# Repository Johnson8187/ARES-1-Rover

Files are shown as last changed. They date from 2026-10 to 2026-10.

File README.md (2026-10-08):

# ARES-1 Rover

低成本、可在高中營隊實作的**直立式雙履帶火星探測車**。主版本 B：WALL·E 式的直立身體與可左右轉的頭，
但把工程放在前面：兩顆 JGA25-370 對角擺放、底盤做成雙層巴士讓學員自備的行動電源躺在馬達正上方、頭部伺服只負責轉不負責扛。

**整台車是 3 mm 椴木合板雷切＋白膠，零 3D 列印**：46 片合板，30 × 45 cm 的板子一台 2 張（**3 台一起排只要 5 張**）、雷射約 30 分鐘就切完一台；履帶和輪子用廠商套件。

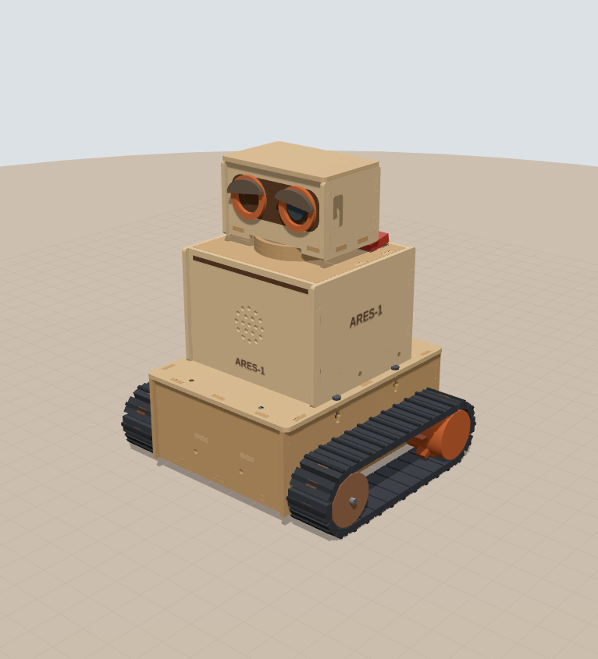
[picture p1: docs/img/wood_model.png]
木板版 3D 模型


| | |
|---|---|
| 外形 | 179 × 160 × 207 mm，約 955 g（含 10000 mAh 行動電源），重心高 61 mm |
| 結構 | 3 mm 椴木合板 46 片，榫接＋白膠；切縫補償、榫孔間隙都可在網頁調，SVG／DXF 直接下載 |
| 驅動 | 2 × JGA25-370 6 V（霍爾編碼器回授）＋ DRV8870 雙路，廠商履帶套件（可拼接，尺寸待量測） |
| 大腦／眼睛 | GOOUUU ESP32-S3-CAM 整塊裝在頭裡，真鏡頭就在右眼，跟頭一起轉 |
| 頭部 | SG92R 直接由 ESP32 驅動（不需伺服驅動板），±45°（機械限位 ±55°） |
| 聲音 | INMP441（頭部）＋ MAX98357A ＋ Ø40 喇叭，I2S 共用時脈 |
| 電源 | 學員自備 PD 行動電源（電池艙 85 × 27.5、尾端開放）→ CH224K 誘騙 9 V → DRV8870（PWM 上限 66 %）＋ Mini560 5 V；編碼器 3.3 V 由 AMS1117 供應 |

## 內容

| 路徑 | 說明 |
|---|---|
| [`web/index.html`](web/index.html) | 互動式 3D 工程網頁（Three.js）：視角、爆炸圖、透明外殼、剖面、配線、點選規格、參數調整、干涉檢查、重心、鏡頭視野、組裝步驟、**雷切排版與 SVG／DXF 下載** |
| [`laser/`](laser) | 預設參數的雷切檔（30 × 45 cm 板）：切縫測試片、一台 2 張、3 台一起 5 張，SVG＋DXF；`parts.csv` 零件清單；`export.mjs` 重產工具 |
| [`docs/LASER.md`](docs/LASER.md) | **雷切與組裝指南**：測試片怎麼量、雷切設定、哪裡上膠、常見問題 |
| [`docs/DESIGN.md`](docs/DESIGN.md) | 工程設計書：方案比較、分層、旋轉機構、穩定性、配線與 GPIO、尺寸狀態、風險、待補量清單、BOM、組裝 |
| [`cad/`](cad)、[`docs/PRINTING.md`](docs/PRINTING.md) | **備案**：改木板之前的 3D 列印版（OpenSCAD＋STL＋試配套件），幾何跟現在的木板版不完全一樣 |
| [`firmware/ares1_bringup/`](firmware/ares1_bringup) | 腳位定義＋硬體上線測試程式（馬達、伺服、喇叭、麥克風、9 V 電源監測、編碼器堵轉保護） |

## 快速開始

1. 用瀏覽器打開 `web/index.html`（需要網路載入 Three.js）。
2. 「參數 → 行動電源」選或輸入自己那一顆的尺寸，看「檢查」分頁的電池艙、干涉與穩定性結果；「規格」分頁有待量測清單。
3. 要雷切時先看 [`docs/LASER.md`](docs/LASER.md)：先切 `laser/ARES1_test.svg` 量板厚和切縫，填進網頁「雷切」分頁，再下載正式板的 SVG／DXF。
4. 組裝照網頁「組裝」分頁的 16 步；哪裡上膠、哪裡不要上膠見 `docs/LASER.md` 第 5 節。

> 已依商品圖更新 ESP32-S3-CAM（GOOUUU）、JGA25-370、DRV8870、MAX98357A、INMP441、SG92R。
> 仍待量測：**履帶套件的輪徑與中心孔（決定底盤高度）**、CH224K 的 9 V 設定方式、DRV8870 的 VO 是否為限流電壓、學員行動電源尺寸、鏡頭實際位置、減速比、6P 編碼器線腳位、喇叭型式等，詳見 `docs/DESIGN.md` 第 11 節。履帶套件量好之前，先切測試片和頭、身體練手，底盤箱等尺寸改好再切。
> ⚠ CH224K 誘騙板上車前一定要先量到 9.0 V（出廠常是 20 V）。

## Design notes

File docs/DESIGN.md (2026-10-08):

# ARES-1 工程設計書 · 主版本 B（直立式、頭可轉、雙履帶）

> 一句話：把兩顆 64 mm 長的馬達「一前一後斜對角」塞進 110 mm 寬的底盤，底盤做成雙層巴士——
> 下層是馬達和電路，上層整層是學員自備行動電源的「床」，從車尾推進去、長的可以露出尾巴。
> 一顆 13 g 的伺服只負責「轉」、不負責「扛」。直立式的角色感留給頭和身體，穩定性交給底盤。

> 整台車是 **3 mm 椴木合板雷切＋白膠**，46 片、30 × 45 cm 兩張板（3 台一起排 5 張），零 3D 列印（切法與組裝見 [`LASER.md`](LASER.md)）。

木板版 3D 模型

| 項目 | 數值 | 狀態 |
|---|---|---|
| 外形 W × L × H | 179 × 160 × 207 mm | 設計值 |
| 結構 | 3 mm 椴木合板 46 片，榫接＋白膠；一台兩張 30 × 45 cm 板（3 台 5 張） | 設計值 |
| 估計重量 | 約 955 g（含 10000 mAh 薄型行動電源 215 g；合板約 260 g） | 估計 |
| 重心高度 | 60.7 mm（總高 29%） | 估計 |
| 翻覆角 前／後／側 | 42.8° ／ 42.3° ／ 55.7° | 估計 |
| 電源 | 學員自備 PD 行動電源 → CH224K 誘騙 9 V → DRV8870＋Mini560 5 V | 設計值 |
| 續航 | 約 5.4 h（10000 mAh、平均 5.8 W） | 估計 |
| 離地間隙 | 11.0 mm（側壁下緣） | 設計值 |
| 頭部轉角 | ±45°（機械限位 ±55°） | 設計值 |
| 鏡頭 | 在右眼，離地約 184 mm，俯角 10° | 設計值 |
| 履帶 | 廠商套件（可拼接）；模型暫用節距 12.5、寬 30、每邊 28 節 | 待量測 |

互動式 3D 模型：`web/index.html`（直接用瀏覽器開，需要網路載入 Three.js）。
雷切檔：`laser/`（預設參數的 SVG／DXF），或在網頁「雷切」分頁改板厚、切縫、板材大小後直接下載。
3D 列印版（`cad/`、`PRINTING.md`）保留當備案，幾何是改木板之前的版本。

尺寸標記：**[C] 已確認**（你提供的或商品圖）、**[E] 估計**、**[M] 待量測**、**[D] 設計值**（我選的，可以改）。

### 目前已依實物資料更新的零件

| 零件 | 從照片確認的事 |
|---|---|
| GOOUUU ESP32-S3-CAM（N16R8） | 2 × 20 排針絲印、OTG＋TTL 兩個 USB-C 在同一端、板載 WS2812、天線突出 PCB 約 4 mm、**相機是軟排線接的，平常貼在模組鐵殼上，偏天線端約 20 mm** |
| JGA25-370 | **6 V 版**、軸根 Ø7 銅套、D 切面 3.5、M3 孔距 17、編碼器 6P 接頭在編碼器蓋側面 |
| DRV8870 雙路模組 | 端子 VM G OUT1–4 在一條長邊、排針 IN1–4 VO G S1 G S2 G 在另一條長邊、板上 LM317M 可調輸出 VO、0.1 Ω 取樣電阻 |
| MAX98357A | 腳位 LRC BCLK DIN GAIN SD GND Vin，上方兩孔距 12.6、孔心到底邊 16.7 |
| INMP441 | 10 × 10，腳位 L/R WS SCK｜GND VDD SD，收音孔在元件面（金屬殼上） |
| SG92R | 23.2 × 12.1 × 22.7、耳片跨距 32.1、含軸總高 30.5、含線約 13 g |

---

## 0. 常見問題（先回答你問的）

### 3D 列印太貴，改成木板雷切可以嗎？

**可以，而且整台車都改成雷切了。** 3 mm 椴木合板榫接＋白膠，46 片、30 × 45 cm 兩張板，雷射約 30 分鐘。
列印最貴的其實不是線材，是**機器時間**：一台車要印十幾到二十幾小時，十台就是一台印表機印一週；雷切一個下午切完全部。

改成木板時重新設計的地方：

| 原本（列印） | 現在（合板） | 為什麼 |
|---|---|---|
| 一體成形底盤槽 | 底板＋左右側壁＋前後壁榫接成箱子，側壁在最外層兼馬達座 | 平板只能做「箱子」，馬達孔、惰輪長槽都直接切在側壁上 |
| 4 根立柱＋熱熔螺母 | 側壁頂邊 4 個 **T 型槽**（M3 螺帽塞進橫槽），上身底板從上面鎖 | 雷切木作的標準鎖法，不用烙鐵 |
| 列印托盤＋M2.5 自攻 | 合板托盤，前端榫頭插前壁、後端落在後壁開口，**不上膠不鎖** | 要修下層的線，抬起來就拿出來 |
| 喇叭墊高環 | 喇叭直接黏在外殼前板背面 | 前板就是音箱面板，少一個零件 |
| 頸座軸環（一體） | 兩片合板環疊黏在頂板上，對位圓用雷射淺劃 | 木頭磨木頭：砂紙磨順＋抹蠟 |
| 頭罩＋後蓋（PETG） | 四面牆＋底板榫接；上蓋＋定位板直接卡進去，不用螺絲 | 臉上的護目鏡用雷雕，眼睛是黏上去的小件 |
| ESP32 角座 | 兩片卡板，PCB 兩端卡進十字孔 | 十字孔中間讓出 USB 與天線 |
| 列印履帶與鏈輪 | 廠商履帶套件 | 營隊已經買了 |

雷切檔是**從 3D 模型直接產生**的：每個榫頭穿過哪一片板，程式就在那片板上挖榫孔（每邊留 0.05 mm），再加上切縫補償、真實形狀排版（小零件塞進大零件的孔和缺口）、文字轉外框。
改任何參數（包括實測板厚），模型、檢查、雷切檔一起變。網頁「檢查 → 製造」會確認每個榫頭都有榫孔、孔不會破邊、孔跟孔不會黏在一起，並把 46 片板在 3D 裡每 2 mm 掃一次，確認沒有兩片佔到同一個空間（這一步抓到了頭部裙邊撞到前後牆下緣，已經在牆下緣挖缺口解決）。

### 新電源方案（PD 行動電源 → CH224K 9 V）可行嗎？

**可行，而且比 2S 18650 更適合營隊**：不用管鋰電池充電與保護板，學員帶自己的行動電源就好。但有 5 件事一定要做對：

| # | 風險 | 做法 |
|---|---|---|
| 1 | CH224K 板子出廠常設 **20 V 或 12 V** | 上車前先單獨接行動電源，三用電表量到 **9.0 V** 才接（設定方式要看你那塊板子：跳線、電阻或撥碼）[M] |
| 2 | 行動電源不支援 PD、或用了 A-to-C 線 → 只有 5 V | DRV8870 要 ≥ 6.5 V 才會動。GPIO1 量 9 V 匯流排，**< 7 V 就停車、亮紅燈、序列埠提示「PD 沒成功」** |
| 3 | 20 W 上限（9 V 最多 2.2 A） | 平常約 6 W 沒問題；最壞（兩邊堵轉＋伺服堵轉＋喇叭大聲）約 25 W。驅動板可變電阻轉最小（限流約 1.25 A）＋ PWM 上限 66 % ＋ **編碼器堵轉保護 0.3 s 斷電** |
| 4 | 行動電源電流太小會自動關機 | ESP32＋相機平常 9 V 端約 0.1 A，勉強在門檻上。韌體不用 deep sleep；真的被關掉就按一下行動電源 |
| 5 | 馬達是 6 V | 9 V × PWM 66 % ≈ 6 V；0.25 s 軟啟動。韌體 `MOTOR_MAX = 0.66`，不要拿掉 |

另外兩個重要修正：

- **編碼器的 3.3 V 改用 AMS1117-3.3**（從 Mini560 的 5 V 降）。DRV8870 模組的 VO 很可能就是晶片的 VREF（限流設定）：0.1 Ω 取樣下限流 ≈ VO ÷ 1 Ω，LM317M 最低 1.25 V → 最低 1.25 A。所以 **VO 不要拿去接任何東西，可變電阻轉到最小**（最安全的限流）。這點等板子回來用三用電表確認 [M]。
- **9 V 側加 C1 1000 µF／25 V**，並在 DRV8870 的 VM／G 端子上。馬達啟動、反轉的電流尖峰會讓行動電源以為短路而斷電，這顆電容幫它擋掉。

### 行動電源要放哪？掛在外面不是比較好換嗎？

我在模型裡兩種都算了（網頁「參數 → 行動電源 → 掛背後（比較用）」可以直接切）。同一顆 10000 mAh 薄型、總高相同：

| | **放電池艙（主方案）** | 掛在身體背後 |
|---|---|---|
| 重心高 | **60.7 mm** | 72.3 mm（＋12） |
| 重心前後 | 幾乎在兩軸中間（−0.5 mm） | 往後 15.7 mm |
| 急加速後仰門檻 | **8.9 m/s²** | 5.4 m/s² |
| 履帶最大抓地 μg | 6.9 m/s² | 6.9 m/s² |
| 結果 | 抓地力先打滑，不會翻 | **猛加速或上坡會往後翻**（後翻角 29.0°，比打滑角 35° 還小） |

掛背後唯一的好處是好拿，但重心又高又偏後，還會擋住外殼拆裝。**電池艙其實一樣好換**：拔線、撕開魔鬼氈、往後抽，不用拆任何東西。

### 每個學員的行動電源都不一樣大，怎麼辦？

把底盤想成**雙層巴士**：下層是馬達、驅動板、電源區；上層整層都是行動電源的「床」。

- **寬 85 mm × 高 27.5 mm 以內都放得進去**（左壁凸緣到右緣立板 85、托盤到上身底板 28）。市售 5000–20000 mAh 幾乎都在這個範圍。
- **長度不限：後面整個打開（開尾）**。電池艙長 152 mm，比較長的直接從車尾露出來；離去角在露出 40 mm 內都還有 36° 以上，營隊坡道 ≤ 20° 沒問題。
- **太薄**：兩條 20 mm 背對背魔鬼氈穿過托盤側邊的扣孔拉緊。
- **太短**：前面塞合板疊片（3 mm 一片可疊，或一塊泡棉），把它推回中間。網頁「檢查 → 行動電源前後位置」會算建議長度。

| 常見行動電源（典型值） | 外形 | 重量 | 重心高 | 建議前方墊塊 | 續航 |
|---|---|---|---|---|---|
| 5000 mAh 小型 | 98 × 63 × 15 | 120 g | 62.1 mm | 約 20 mm | 約 2.7 h |
| 10000 mAh 方塊 | 105 × 66 × 25 | 200 g | 62.1 mm | 約 20 mm | 約 5.4 h |
| **10000 mAh 薄型（預設）** | 148 × 70 × 15 | 215 g | 60.7 mm | 不用 | 約 5.4 h |
| 20000 mAh 大容量 | 155 × 74 × 27 | 420 g | 60.7 mm | 不用（尾巴露出 3 mm） | 約 10.8 h |

自己那一顆不在表上？網頁「參數 → 行動電源」直接輸入長寬厚和重量，所有檢查會即時重算。

**行動電源的條件**：支援 USB PD、背面標示有 **9V⎓2A**（或寫 18 W／20 W 以上）、有 **C 孔輸出**。只有 A 孔、或只有 5 V 的不能用。

### 怎麼換行動電源？

1. 關掉頂板上的開關。
2. 拔掉車尾的 USB-C 短線。
3. 撕開兩條魔鬼氈。
4. 行動電源直接往後抽出來，換一顆推到底、綁好、插線。

整個過程**不用拆外殼、不用拆頭、也不用把車翻過來**。不想拔也可以：輸入孔朝後放，直接插充電器在車上充。
網頁「顯示 → 換行動電源示範」會把這個動作跑給你看。

### SG92R 夠力嗎？要不要換 MG996R？

**SG92R 夠，而且比 MG996R 更適合。**

- 頭部（合板頭殼＋底盤＋ESP32＋麥克風＋線）約 70 g，轉動慣量約 50 kg·mm²。
- 就算用 SG92R 最快的速度（0.1 s／60°）急轉急停，只需要約 21 mN·m；SG92R 在 4.8 V 約 245 mN·m，**安全係數約 12 倍**。
- 頭的重量和撞擊由頂板的軸環／頭部裙邊承受，伺服軸只負責轉，不會被壓歪。

MG996R 反而是負擔：55 g（重心變高）、堵轉電流約 2.5 A（20 W 行動電源更吃緊、ESP32 容易重開機）、尺寸大到頸部要重畫，而且便宜版常有抖動。
MG996R 可以留給未來真的要扛東西的手臂。

### 一顆伺服需要伺服驅動板嗎？

**不需要。** ESP32-S3 的 LEDC 可以直接輸出 50 Hz PWM，SG92R 吃 3.3 V 訊號沒問題。只要注意：

- 伺服的電源（紅線）接配電板的 5 V，**不要**從 ESP32 的 5V 腳取電。
- 伺服的地（棕線）和 ESP32 共地。
- 訊號（橘線）接 GPIO2。

LU9685 這類 16 路 PWM 板是給「很多顆伺服」或「沒有 PWM 腳」的情況，這台車用不到。

### 馬達的霍爾編碼器要接回 ESP32-S3

可以，而且值得：有了速度回授，兩邊履帶可以跑一樣快，車子才走得直；新電源方案還要靠它做堵轉保護。做法見第 7.3 節，重點是：

- **A 相先接**：左馬達 → GPIO19、右馬達 → GPIO20（OTG 口的腳位，所以改用 TTL 口燒錄）。方向用馬達指令判斷就好。
- **B 相選配**：GPIO3、GPIO46。GPIO46 在燒錄時必須是低電位，燒不進去時拔掉 J2 或把輪子轉一下。
- **編碼器一定要吃 3.3 V**：ESP32-S3 的腳位不耐 5 V。由 AMS1117-3.3 供電，每條訊號線再串 1 kΩ。

---

## 1. 三種直立式配置，為什麼選 B

| | A 同軸後置 | **B 對角馬達（主方案）** | C 長頸桅杆 |
|---|---|---|---|
| 馬達擺法 | 兩顆都在車尾、同一軸線對頂 | 左馬達在後、右馬達在前，前後錯開 | 同 B |
| 兩馬達干涉 | 內寬 110 會**重疊 18 mm**，要加寬到 ≥ 132 | **完全錯開**，最近距離 86.5 mm | 同 B |
| 整車寬 | 205 mm | **181 mm** | 181 mm |
| 重心 | 偏後 8 mm | 前後平衡（z 偏移 −0.6 mm） | 高 10 mm（71.6 mm） |
| 換行動電源 | 電池艙同 B，但車尾下層被馬達佔滿，USB-C 只能接到前面 | **車尾抽出，長的可以露出尾巴** | 同 B |
| 頭部 | 同 B | 線束最短、最穩 | 桅杆會晃、線束多 70 mm |
| 鏡頭 | 同 B | 離地 182 mm | 離地 252 mm，看得最遠 |
| 結論 | 不選 | **主方案** | 備選：比賽需要看遠時再用 |

C 其實不會翻（翻覆門檻 7.6 m/s² 仍大於抓地力 6.9 m/s²），但安全餘裕從 27% 掉到 10%，而且頭部多一根 70 mm 的槓桿，每次急停都會點頭。

網頁「參數 → 配置方案」可以切換 A/B/C，A 在 110 mm 內寬時會直接亮紅色干涉。

---

## 2. 分層與高度

座標：X＝車子左側、Y＝向上、Z＝車頭方向，原點在地面中心。

| 層 | 高度範圍 (mm) | 內容 |
|---|---|---|
| 底盤下層 | 0 – 37.5 | 履帶、底盤箱（合板榫接）、兩顆 JGA25-370、DRV8870＋C1、電源區（CH224K、Mini560、AMS1117） |
| 底盤上層（電池艙） | 37.5 – 70 | 托盤、行動電源、魔鬼氈；右側線材通道與 J1/J2；上身底板 |
| 身體層 | 71.5 – 149.5 | 上身骨架、外殼套筒（高 78）、喇叭、MAX98357A、配電板、開關、SG92R |
| 頭部層 | 149.5 – 207 | 頸座軸環、頭部底盤、頭殼、上蓋、ESP32-S3-CAM、INMP441 |

關鍵高度：軸心 24.2、馬達頂 36.7、履帶頂 48.5；側壁下緣 11.0、底板 14–17、托盤 37.5–40.5、電池艙 40.5–68.5、上身底板 68.5–71.5；
身體 71.5–149.5；伺服底 128.1、舵盤頂＝頭部底板底 159.0、鏡頭中心 184.0、頭頂 207.0。

為了讓出 28 mm 的電池艙，身體從 96 縮成 78 mm，**總高不變**。降壓模組搬到底盤電源區，身體裡反而更空。

---

## 3. 底盤層

### 3.1 履帶與輪子（廠商套件）

營隊已經買了履帶套件：履帶是一節一節拼的，長度可以自己加減。模型暫時用「節距 12.5、10 齒驅動輪（節圓 Ø41）、寬 30、軸距 111.5 → 每邊 28 節」算，
**輪徑決定輪軸高度、底盤箱高度和離地間隙**，套件量好之後要改參數（網頁「參數」）再切底盤箱。

要量的：驅動輪外徑（含齒）、齒數、輪寬、中心孔（圓／D 形／六角、幾 mm）；惰輪外徑、寬、中心孔；履帶節距（量 10 節 ÷ 10）、寬、厚。
驅動輪中心孔不是 Ø4 D 形的話，用聯軸器或法蘭轉接到 JGA25-370 的軸。

### 3.2 底盤箱與馬達固定

- 底盤箱是 14 片 3 mm 合板：底板夾在四面牆中間、四邊榫頭插進牆；**左右側壁在最外層**，前後各多 3 mm 包住前後壁，同時是馬達座與惰輪軸座。
- 左馬達在車尾（z = −55.75），右馬達在車頭（z = +55.75）。兩個 M3 孔（孔距 17）**左右（水平）排列**，編碼器 6P 接頭水平朝車身中央（上面 0.8 mm 就是托盤）。
- 用 **M3 × 6 圓頭** 從側壁外面鎖，穿過 3 mm 合板後進入減速箱約 3 mm。軸根 Ø7 銅套凸台坐進側壁 Ø8.4 軸孔。
- 馬達尾端靠在兩片合板托柱上，束線帶綁住。底板在馬達正下方開缺口，讓馬達低到「軸高 − 半徑」。
- 側壁比底板往下多 3 mm（底板的榫頭才插得進側壁），所以離地間隙是 11.0 mm，由側壁下緣決定。

### 3.3 上身怎麼鎖在底盤上：T 型槽

側壁頂邊有 4 個 T 型槽（左右各 2，z = ±30）：豎槽 3.4 寬、13 深，中間一條 5.8 × 2.6 的橫槽放 M3 螺帽。
上身底板（比側壁外面再寬 2.5 mm）從上面用 **M3 × 12** 鎖下來咬住螺帽。螺帽比 3 mm 板寬，會凸出側壁兩面一點點，這是正常的。

### 3.4 電池艙（行動電源）

| 項目 | 設計 |
|---|---|
| 托盤 | 3 mm 合板、底面在 37.5（馬達頂 +0.8）；前端兩個榫頭插進前壁，左邊架在凸緣上、右邊靠小立板、後端落在後壁開口下緣。**不上膠不鎖**，抬起來就拿出來 |
| 可用空間 | 寬 85（右緣立板到左壁凸緣）× 高 27.5 × 長 152，**後方不封口** |
| 擋塊 | 前壁就是擋塊；短的行動電源前面塞合板疊片（3 mm 一片）或泡棉 |
| 固定 | 兩條 20 mm 背對背魔鬼氈，扣孔 3 組（z = −55、−10、35），行動電源短的時候用前面兩組 |
| 右緣立板 | 高 8，黏在托盤上，兼行動電源導軌與線材通道的牆 |
| 線材通道 | 右側 16 mm 寬，從地板直通上身底板的 6 × 26 長孔；J1/J2 放在裡面 |
| 後壁 | 上半部整個打開（行動電源進出）；下半部 13.5 × 7.6 孔讓 CH224K 的 USB-C 母座伸出 |

### 3.5 DRV8870 雙路模組

| 項目 | 設計 |
|---|---|
| 位置 | **右側** x = −51 … −21、z = −36 … 12；底板開 4 個 Ø3.2 孔，5 mm 尼龍隔離柱墊高，M3 從底板下面鎖 |
| 孔距 | 40.8 × 22.8（照片標 R3.6 圓角，孔心在圓角中心）[E] |
| 方向 | **藍色端子朝車身中央、VM 在後端（靠電源區）**；排針那一長邊在線材通道正下方，杜邦頭上方有 30 mm 可以往上彎線 |
| 接線 | VM／G ← 9V_SW（並 C1 1000 µF）；OUT1/2 → 右（前）馬達；OUT3/4 → 左（後）馬達；IN1–4 ← J2 |
| VO | **不接任何東西**。很可能就是 VREF（限流）：可變電阻轉到最小 ≈ 1.25 A [M] |
| S1／S2 | 用途待確認（可能是電流取樣輸出），第一版不接 |

控制：IN1 = PWM、IN2 = 0 前進；IN1 = 0、IN2 = PWM 後退；兩腳都 0 滑行、都 1 煞車。

### 3.6 電源區（下層右後角）

| 模組 | 位置 | 說明 |
|---|---|---|
| CH224K 誘騙板 | 右後角，坐在合板墊片上、USB-C 母座從後壁小孔伸出 | 設 9 V；外形約 12 × 25 [M] |
| Mini560 | CH224K 旁邊 | 9 V → 5 V，標示 5 A [E]；固定 5 V 版免調 |
| AMS1117-3.3 | 右側通道下方 | 5 V → 3.3 V，只給兩顆編碼器 |
| C1 1000 µF／25 V | 躺在 DRV8870 端子旁、腳朝後 | 並在 VM／G 上 |

行動電源的 C 孔朝後，用 10–15 cm 的 C-to-C 短線從車尾繞下來插 CH224K。桌上測試時可以直接插 PD 充電頭（20 W 以上）。
底板上雷雕了每個模組的位置框（藍色淺劃線）：先黏 3 mm 合板墊片，再用泡棉雙面膠貼模組（Mini560、AMS1117 多半沒有安裝孔）。

---

## 4. 身體層

- **上身骨架**：上身底板（161 × 121 × 3）兼電池艙上蓋；一片脊板＋兩片側翼用榫頭插進底板和頂板，白膠固定。右後方 6 × 26 長孔對準線材通道。拆 4 顆 M3（T 型槽），上身（含頭）整組拿起，中間只連 J1（電源）、J2（馬達與編碼器訊號）。
- **外殼套筒**：110 × 100 × 78、上下開口，左右側板在最外層、前後板內縮 3 mm（像相框）。側面 4 顆 M3 × 8 鎖進側翼上壓入的六角螺帽。頭 84 × 54、軸環 Ø50、限位柱半徑 33，全在開口之內，**拆外殼不用拆頭**。

| 模組 | 位置 | 固定 |
|---|---|---|
| 喇叭 Ø40 × 20 [E] | 外殼前板背面，對準圓孔格柵 | 熱熔膠黏在前板上（線留 12 cm，外殼才拔得起來） |
| MAX98357A | 喇叭旁，喇叭線 < 8 cm | 上方兩孔 M2（孔距 12.6 [C]） |
| 配電洞洞板 | 右翼內側（SS34、470 µF ×2、9 V 監測分壓、4 顆 1 kΩ 編碼器保護電阻） | 束線帶穿右翼的 4 個小孔 |
| 開關 KCD1 | 頂板左後角，按鈕朝上 | 卡入 19 × 13 開孔 |
| SG92R | 倒吊在頂板下方 | 耳片 2 × M2 自攻 |

⚠ 你的 MAX98357A 商品組合裡附的是**長方形腔體喇叭**。如果你用的是那一顆而不是 Ø40 圓形喇叭，請告訴我尺寸，前板的格柵要改成長方形。

---

## 5. 頭部層（主版本重點）

### 5.1 頭型：右眼就是真鏡頭

GOOUUU 板的 OV2640 不是焊死在板子中間，而是用橘色軟排線接在板子中段的 FPC 座，相機本體平常貼在 WROOM 模組的鐵殼上，
**離 PCB 中心約 20 mm、偏天線那一端**。PCB 橫放在頭裡時，這個位置剛好就是一隻眼睛。

所以頭部設計成一對對稱的眼圈：**右眼的瞳孔就是真的鏡頭**，左眼是合板切的造型瞳孔（塗深灰）。臉上一片深色護目鏡是雷雕出來的。
兩眼上方各有一片可替換的眼瞼，角度就是表情，營隊可以讓學員自己設計。

軟排線的好處：鏡頭和眼圈中心差幾 mm 時，直接把相機模組挪過去，用雙面膠貼好就對準了。
（網頁「鏡頭偏離 PCB 中心」小於 12 mm 時，會自動退回「兩眼都是造型、鏡頭藏在護目鏡中間」的版本。）

### 5.2 旋轉機構：伺服只轉、不扛

```
頭部底板（合板）──┬── 2×M2 ── Ø20 圓舵盤 ── SG92R 花鍵
                  └── 裙邊 3 片疊黏 ID51/OD57（下垂 9）── 套住 ──> 頸座軸環 2 片疊黏 ID42/OD50（高 6）
```

- 伺服從頂板下方塞入，耳片貼頂板底面，只有花鍵凸台露出來。
- 頭的重量由花鍵承受（約 70 g），**側向力與撞擊由軸環／裙邊承受**，徑向間隙 0.5 mm。木頭磨木頭：兩邊都用 400 號砂紙磨順、抹一點蠟。
- 兩根限位柱＋裙邊限位指：軟體 ±45°、**機械限位 ±55°**。
- 裙邊 Ø57 比頭部深度（54）大一點，前面會像下巴一樣露出約 2.5 mm；最上面那片裙邊跟頭殼前後牆的下緣同高，所以前後牆下緣各挖一個缺口讓它通過（3D 互撞檢查抓到的）。
- 組裝時先用測試程式把伺服轉到 90° 再裝舵盤。

### 5.3 線束怎麼過一個被伺服佔住的轉軸

1. 頭部底板在轉軸後方 16 mm 開 Ø8 孔（杜邦頭可以一顆一顆穿）。
2. 頂板同一位置開**腎形窗口**（r = 9 … 20.5，只在 z ≤ −7.5，避開伺服耳片）。
3. 線束現在是 15 芯（加了編碼器），外包螺旋套約 Ø7。頭轉到 ±45° 時線束邊緣在 57.6°，窗口可用到 62.1° → **餘裕 4.4°**。
4. 身體內留 U 形餘長圈。頭轉 ±45° 時線束頂端只橫移約 ±11 mm。

### 5.4 ESP32-S3-CAM 安裝（GOOUUU）

- PCB 橫放、俯角 10°。USB 端朝頭部**左側**、天線端朝**右側**（天線突出 PCB 約 4 mm，右側牆內還有 1.9 mm 空隙）。
- 兩片合板卡板插在頭部底板上，PCB 兩端卡進卡板的十字孔（上下角卡住，中間讓出 USB 與天線）。先把 PCB 塞進兩片卡板，再三個一起插進底板。
- 排針朝後，杜邦頭插好後點熱熔膠。深度預算：鏡頭 11 [M] ＋ PCB 1.6 ＋ 排針 8.5 ＋ 杜邦 14 ＋ 彎線 6 = 41.1，頭內可用 44.5 mm。
- **板上只有一支 GND**（右排最下面）：5V 與 GND 用 24 AWG，麥克風的 GND 從同一點分出來。
- USB：頭殼左側板 9 × 20 mm 開孔，OTG、TTL 兩個 USB-C 都露出來。**用 TTL 口燒錄**（CH340 會自動重置，最穩）。
- 散熱：頭後板 7 道散熱槽；木頭不像 PLA 會在 55 °C 變軟。

### 5.5 麥克風放頭部

| 位置 | 到喇叭 | 到馬達 | 結構振動 |
|---|---|---|---|
| **頭頂內側（預設）** | 109 mm | 181 mm | 和喇叭隔著伺服，不共振 |
| 身體上後方 | 約 104 mm | 約 136 mm | 和喇叭共用外殼，會收到喇叭振動 |

INMP441 的收音孔在元件面（金屬殼上），所以**金屬殼朝上**貼在頭頂 3 個 Ø1.5 小孔下面。排針不要焊，5 條線直接焊在焊盤上比較薄。
轉頭就是「轉耳朵」。網頁可以切回身體版本。

### 5.6 鏡頭視野

OV2640 對角約 66° [M] → 水平約 55°、垂直約 43°。俯角 10° 時正前方地面最近看到約 299 mm；頭轉 0° 與 45° 時畫面都不會拍到車身。

---

## 6. 特別檢查（你點名的 5 項）

| # | 檢查 | 結論 | 數字 |
|---|---|---|---|
| 1 | 兩顆 JGA25-370 是否干涉 | **不干涉** | 對角擺放，前後相距 86.5 mm；馬達尾端離對側側壁 46 mm。同軸擺法在 110 mm 內寬會重疊 18 mm |
| 2 | 頭轉時 ESP32 與線材會不會卡 | **不會** | PCB 在頭內跟著轉；15 芯線束窗口餘裕 4.4°；頭底離身體頂 9.5 mm |
| 3 | 重心是否過高 | **不高** | 重心 60.7 mm，只有總高 29%。行動電源躺在 40.5–55.5 mm、馬達與履帶在 37 mm 以下 |
| 4 | 底盤寬度是否撐得住 | **撐得住** | 側翻角 55.7°；前後翻門檻 8.9–9.1 m/s²，大於履帶最大抓地 6.9 m/s²，會先打滑不會翻 |
| 5 | 換電池與 USB | **方便** | 行動電源從車尾抽出；USB 從頭部左側直接插 |

穩定性算法：把 34 個零件的質量與位置加權求重心；支撐面取履帶外緣（x = ±90.5）與兩輪軸心（z = ±55.75）。
翻覆加速度 = g × 水平距離 ÷ 重心高；履帶最大加速度 ≈ μg（μ = 0.7 [E]）。韌體仍限制加速度（上線測試程式 0 → 全速 0.25 s），因為坡道、推土板、撞牆都會吃掉餘裕。

---

## 7. 配線設計

### 7.1 電源樹

```
學員自備 PD 行動電源（C 孔）
 └─ C-to-C 短線 ─ 後壁 USB-C ─ CH224K 誘騙 9 V ─ J1（9V_RAW）─ 頂板開關 ─ J1（9V_SW）
      ├─ C1 1000 µF／25 V ─ DRV8870 VM（馬達，PWM 上限 66 %；VO 不接、可變電阻最小）
      ├─ Mini560 IN → 5 V ─ J1（5 V × 2 pin）
      │    ├─ AMS1117-3.3 → 兩顆馬達編碼器 VCC
      │    └─ 配電板
      │         ├─ SG92R（旁邊 470 µF）
      │         ├─ MAX98357A VIN（旁邊 470 µF）
      │         └─ SS34 → 頸部線束 → ESP32-S3-CAM 5V 腳（約 4.6 V）
      │                                   └─ 板上 3.3 V → INMP441
      └─ 100k / 33k 分壓 → GPIO1（9 V → 2.23 V；PD 沒成功 5 V → 1.24 V）
GND：配電板單點匯流，底盤經 J1 回 CH224K 負極
```

- J1 改成 **JST-XH 6P：9V_RAW、9V_SW、GND × 2、5 V × 2**（每 pin 約 3 A；9 V 最多 2.2 A 用單 pin）。
- 保險絲改成選配：行動電源本身有過流保護；想加就在 CH224K 輸出串 3 A 自恢復保險絲。
- SS34：插 USB 燒錄時 USB 的 5 V 不會倒灌到 Mini560。
- 韌體：9 V < 7.0 V 停車亮紅（PD 沒成功）、< 8.3 V 亮黃；編碼器 0.3 s 沒脈衝就斷電（堵轉保護）。9 V 不會隨行動電源電量慢慢掉，電量看行動電源自己的燈。

### 7.2 GPIO 分配（GOOUUU ESP32-S3-CAM，已依排針絲印核對）

| GPIO | 排針 | 用途 | 狀態 |
|---|---|---|---|
| 1 | 右 | 9 V 電源監測（ADC1_CH0，PD 有沒有成功） | D |
| 2 | 右 | SG92R 訊號（50 Hz） | D |
| 47 | 右 | 右（前）馬達 → 模組 IN1 | D |
| 38 | 右 | 右（前）馬達 → 模組 IN2 | D |
| 14 | 左 | 左（後）馬達 → 模組 IN3 | D |
| 21 | 右 | 左（後）馬達 → 模組 IN4 | D |
| 39 | 右 | I2S BCLK（麥克風 SCK＋功放 BCLK 共用） | D |
| 40 | 右 | I2S WS（麥克風 WS＋功放 LRC 共用） | D |
| 41 | 右 | I2S DOUT → MAX98357A DIN | D |
| 42 | 右 | I2S DIN ← INMP441 SD | D |
| 19 | 右 | 左馬達編碼器 A（OTG 的 D−） | D |
| 20 | 右 | 右馬達編碼器 A（OTG 的 D+） | D |
| 3 | 左 | 左馬達編碼器 B（選配） | D |
| 46 | 左 | 右馬達編碼器 B（選配，⚠ 燒錄時必須低電位） | M |
| 48 | 右 | 板載 WS2812，當狀態燈 | C |
| 43 / 44 | 右 | TX0 / RX0 → CH340（TTL 口，燒錄與序列埠） | C |
| 4–13、15–18 | 兩排 | 相機（與 ESP32-S3-EYE 相同） | C |
| **35 / 36 / 37** | 右 | **Octal PSRAM，排針上有但絕對不能接** | C |
| 0、45 | 右 | Strapping（BOOT、Flash 電壓），不接 | C |

可用 14 支，用 12 支（含編碼器 A 相）＋選配 2 支。I2S 必須讓麥克風和功放共用 BCLK/WS（同一個 I2S0 全雙工，取樣率相同，建議 16 kHz）才夠。
**不需要 LU9685**：只有 1 顆伺服，ESP32 直接輸出。

### 7.3 霍爾編碼器怎麼接

JGA25-370 的編碼器線是一條 6P（常見：M+、M−、編碼器 VCC、GND、A、B，**每家顏色不同，請拍給我對**）：

| 線 | 接到 |
|---|---|
| M+ ／ M− | DRV8870 OUT（右馬達 OUT1/2、左馬達 OUT3/4） |
| VCC ／ GND | AMS1117-3.3 的 3.3 V ／ GND（都在底盤電源區） |
| A ／ B | J2 → 配電板串 1 kΩ → 頸部線束 → GPIO19/20（A）、GPIO3/46（B） |

- 第一版只用 A 相，用中斷數脈衝（上線測試程式的 `e` 指令），方向取自馬達指令。
- 為什麼要 3.3 V：編碼器板上的上拉電阻接在 VCC，VCC 是 5 V 時 A/B 就是 5 V，會慢慢燒壞 ESP32-S3。**接之前先用三用電表確認 AMS1117 輸出 3.3 V**。
- 6P 接頭現在水平朝車身中央（馬達兩個 M3 孔左右排列），插頭往中間伸，線沿著托盤底下走到右側通道。
- J2 從 4P 升級成 **JST-XH 8P**（PWM × 4 ＋ 編碼器 × 4）。

### 7.4 接線表（走線長度由 3D 路徑量出，剪線請 +40 mm）

| 線 | 從 → 到 | 線材 | 走線長 |
|---|---|---|---|
| USB-C 短線 | 行動電源 C 孔 → 後壁 USB-C（CH224K） | C-to-C，支援 PD 3 A | 97 mm（買 10–15 cm） |
| 9 V 輸出 | CH224K VOUT／GND → J1 | 20 AWG 紅／黑 | 54 mm |
| 9 V 上身（去回） | J1 → 頂板開關（9V_RAW、9V_SW） | 20 AWG | 124 mm |
| 開關後 9 V | J1(9V_SW) → C1 → DRV8870 VM／GND | 20 AWG | 82 mm |
| Mini560 輸入 | C1／VM → Mini560 IN | 22 AWG | 46 mm |
| 5 V 匯流 | Mini560 OUT → J1 → 配電板 | 22 AWG（兩 pin 並聯） | 153 mm |
| 3.3 V 輸入 | Mini560 OUT → AMS1117 | 24 AWG | 53 mm |
| 伺服 | 配電板 3P → SG92R | 原廠線 | 70 mm |
| 功放 | 配電板 → MAX98357A（5V、GND、BCLK、WS、DOUT） | 26 AWG ×5 | 103 mm |
| 喇叭 | MAX98357A → 喇叭 | 24 AWG 雙絞 | 44 mm |
| 右（前）馬達 | DRV8870 OUT1/2 → 6P 接頭 M+／M− | 22 AWG 雙絞 | 66 mm |
| 左（後）馬達 | DRV8870 OUT3/4 → 6P 接頭 M+／M− | 22 AWG 雙絞 | 44 mm |
| 馬達訊號 | 配電板 → J2 → DRV8870 IN1–4 | 26 AWG ×4 | 135 mm |
| 編碼器電源 | AMS1117 3.3 V／GND → 兩顆馬達 VCC／GND | 26 AWG ×2 | 150 mm |
| 左編碼器 | 左馬達 A／B → J2 | 26 AWG ×2 | 86 mm |
| 右編碼器 | 右馬達 A／B → J2 | 26 AWG ×2 | 99 mm |
| **頸部線束** | 配電板 → ESP32 排針（5V、GND、PWM×4、伺服、BCLK、WS、DOUT、9 V 監測、編碼器×4） | 5V/GND 24 AWG＋其餘 26 AWG，15 芯 | 131 mm |
| 麥克風 | ESP32 排針 → INMP441（3V3、GND、SCK、WS、SD） | 28 AWG ×5 | 24 mm |

BCLK 與 WS 在頭內要 Y 型分接（一路到麥克風、一路下頸部到功放）：焊接＋熱縮管。

---

## 8. 拆裝與維修

| 要做的事 | 拆什麼 |
|---|---|
| 換行動電源 | 什麼都不用拆：拔線、撕魔鬼氈、往後抽 |
| 充行動電源 | 什麼都不用拆：輸入孔朝後的話直接插充電器 |
| USB 燒錄 | 什麼都不用拆：頭轉正，插左側 TTL 口（先關電源開關） |
| 看頭內接線 | 頭上蓋直接拔起來（定位板卡在四面牆裡，沒有螺絲） |
| 看身體內部 | 外殼側面 4 顆 M3，套筒往上拔 |
| 換驅動板、馬達、電源模組 | 再拆上身底板 4 顆 M3（T 型槽），抬起一點拔 J1/J2，整個上身拿起來；拿出行動電源，托盤後端抬起來往後抽 |
| 換履帶 | 照套件方式拆節；惰輪 M4 放鬆就能把履帶拿下來 |
| 某一片合板壞了 | 網頁「雷切」只重切那一片（零件清單有編號），幾十秒 |

---

## 9. 尺寸狀態總表

| 元件 | 項目 | 數值 (mm) | 狀態 |
|---|---|---|---|
| JGA25-370 | 本體 Ø25（馬達罐 Ø24.2）／馬達段 31／編碼器蓋 11 | — | C |
| JGA25-370 | 輸出軸 Ø4、突出 12.5、D 切面 3.5、M3 孔距 17 | — | C |
| JGA25-370 | 軸根銅套 Ø7 × 約 2.5 | — | E |
| JGA25-370 | 額定電壓 | 6 V | C |
| JGA25-370 | 減速箱長 L（依減速比）、6P 腳位 | 22 | E ／ M |
| ESP32-S3-CAM | GOOUUU N16R8，PCB 62.6 × 28.3，排針 2 × 20、列距 24.7 | — | C |
| ESP32-S3-CAM | OTG＋TTL 同一端（中心 ±5.6）、WS2812 在 GPIO48 | — | C |
| ESP32-S3-CAM | 天線突出 PCB | 4.3 | E |
| ESP32-S3-CAM | 鏡頭偏離 PCB 中心（軟排線，可調） | −20 | M |
| ESP32-S3-CAM | 鏡頭高出 PCB、背面有無 TF 卡座 | 11 ／ — | M |
| MAX98357A | PCB 17.7 × 19.1、上方孔距 12.6、孔心到底邊 16.7、腳位 | — | C |
| INMP441 | 10 × 10、6 腳、收音孔在元件面 | — | C |
| DRV8870 雙路 | 48 × 30、Ø3 孔、端子與排針排列、LM317M | — | C |
| DRV8870 雙路 | 孔距 | 40.8 × 22.8 | E |
| DRV8870 雙路 | VO 是否＝VREF（限流）、S1／S2 用途 | — | M |
| SG92R | 23.2 × 12.1 × 22.7、跨距 32.1、總高 30.5、約 13 g | — | C |
| SG92R | 耳片下緣高、軸心到本體端、耳片孔距 | 15.9 ／ 5.9 ／ 27.8 | E |
| 行動電源（學員自備） | 外形／重量（預設 10000 mAh 薄型） | 148 × 70 × 15 ／ 215 g | M |
| 電池艙 | 可用寬 × 高 × 長（尾端開放） | 85 × 27.5 × 152 | D |
| CH224K 誘騙板 | 外形、9 V 設定方式 | 約 12 × 25 ／ — | M |
| Mini560 | 外形、固定 5 V 或可調 | 22 × 17 ／ — | E ／ M |
| AMS1117-3.3 模組 | 外形 | 22 × 11 | E |
| C1 | 1000 µF／25 V | Ø10 × 20 | E |
| 喇叭 | 圓形 Ø40 × 20 還是長方形腔體 | — | M |
| 履帶套件 | 驅動輪外徑、齒數、中心孔；履帶節距、寬 | 模型暫用 Ø41、10 齒、12.5、30 | M |
| 椴木合板 | 實際板厚（「3 mm」常是 2.7–3.2） | 3.00 | M |
| 雷切機 | 切縫寬、平台大小 | 0.15 ／ 400 × 300 | M |
| 其他 | 所有合板件尺寸 | 由網頁參數產生（`laser/parts.csv`） | D |

---

## 10. 風險結構

| 等級 | 風險 | 對策 |
|---|---|---|
| 高 | 急煞前翻／急加速後仰 | 行動電源躺在馬達正上方當配重；韌體加速度限制；換大顆行動電源、加推土板或加高頸部後重看「檢查」 |
| 高 | 頸部線束疲勞斷線 | 線束在轉軸後方 16 mm；U 形餘長；機械限位 ±55°；杜邦頭熱熔膠 |
| 高 | CH224K 輸出不是 9 V（出廠常是 20 V） | 上車前單獨量到 9.0 V 才接 |
| 高 | PD 沒成功（只有 5 V）或行動電源自動關機 | 一定用 C-to-C 線；GPIO1 監測 < 7 V 停車亮紅；韌體不用 deep sleep |
| 高 | 編碼器 5 V 燒壞 GPIO | 編碼器只吃 AMS1117 的 3.3 V＋每條 1 kΩ；驅動板 VO 不接 |
| 中 | 20 W 上限：兩邊堵轉＋伺服＋喇叭會超過 | 驅動板可變電阻最小（約 1.25 A）、PWM 上限 66 %、編碼器堵轉保護 0.3 s |
| 中 | 6 V 馬達接 9 V | PWM 上限 66 %（平均約 6 V）、0.25 s 軟啟動 |
| 中 | 每個學員的行動電源不一樣 | 電池艙 85 × 27.5、尾端開放；魔鬼氈＋前方墊塊；網頁先輸入尺寸檢查 |
| 中 | 伺服／喇叭瞬間電流讓 ESP32 重開 | Mini560；伺服、功放旁各 470 µF；ESP32 經 SS34 獨立一路；9 V 端 C1 1000 µF |
| 中 | GPIO46（編碼器 B）影響燒錄 | 先只接 A 相；接 B 相後燒錄失敗就拔 J2 |
| 中 | 接到 GPIO35/36/37 | 這三支是 PSRAM，接線表與排針貼紙標明「不可用」 |
| 中 | 套件驅動輪的孔不合 Ø4 D 軸 | 先量中心孔；不合就用聯軸器／法蘭轉接 |
| 中 | 榫接太緊或太鬆 | 每批板子先切測試片校正板厚、切縫、間隙（`LASER.md` 第 2 節） |
| 中 | 頭內發熱 | 頭後板散熱槽、串流降解析度 |
| 中 | 減速箱 M3 螺絲過長頂到齒輪 | M3 × 6 圓頭，穿過 3 mm 合板後進入約 3 mm |
| 低 | 合板受潮翹曲 | 組好後塗一層水性透明漆或蠟；不要放在大太陽下的車裡 |
| 低 | 離地 11.0 mm | 室內場地；障礙物 ≤ 15 mm |
| 低 | 長行動電源尾巴露出 | 露出 40 mm 內離去角仍 ≥ 36°；倒車撞牆時尾巴先撞 |
| 低 | I2S 共用時脈 | 麥克風與喇叭同取樣率（16 kHz） |

---

## 11. 還需要你補的

1. **學員的行動電源**：請收集大家手上那顆的長 × 寬 × 厚、重量，以及背面有沒有「9V⎓2A」或 20 W 標示。越多筆越好，我可以再微調電池艙。
2. **CH224K 誘騙板**：拍正反面，看它怎麼設定 9 V（跳線、電阻還是撥碼），以及外形尺寸。
3. **Mini560**：拍正反面，確認是固定 5 V 還是可調、外形尺寸。
4. **DRV8870 模組**：板子回來後量 VO（轉可變電阻看是不是從 1.25 V 起跳），並拍背面確認 VO 是否接到 DRV8870 的 VREF、S1／S2 接哪裡。
5. **ESP32-S3-CAM**：鏡頭中心到天線端 PCB 邊的距離（目前估 11 mm → 偏移 −20）、鏡頭頂高出 PCB 多少、背面有沒有 TF 卡座。
6. **JGA25-370**：減速比（決定減速箱長 L），以及 **6P 編碼器線每一條的顏色或絲印**。
7. **SG92R**：卡尺量耳片下緣到底部、軸心到本體端。
8. **喇叭**：Ø40 圓形，還是商品圖裡的長方形腔體喇叭？（尺寸、阻抗、功率）
9. **履帶套件**：驅動輪／惰輪外徑、齒數、寬、中心孔；履帶節距、寬。輪徑決定底盤箱高度，量好再切底盤箱。
10. **雷切機**：平台大小、瓦數、用什麼軟體（LightBurn、RDWorks…）。我可以把排版改成剛好塞滿你們的平台。

---

## 12. 製造清單

**先切 `laser/ARES1_test.svg` 測試片，量好板厚與切縫，再切正式板。** 雷切設定、上膠位置、常見問題見 [`LASER.md`](LASER.md)。

### 12.1 雷切件（3 mm 椴木合板，46 片）

| 字頭 | 組件 | 片數 | 合板重量 |
|---|---|---|---|
| C | 底盤箱：底板、左右側壁、前後壁、托盤凸緣、小立板、4 根托柱、3 片電源墊片 | 14 | 約 73 g |
| T | 電池艙托盤＋右緣立板 | 2 | 約 20 g |
| B | 上身骨架：上身底板、脊板、左右側翼 | 4 | 約 57 g |
| N | 頂板／頸座：頂板、2 片軸環、2 根限位柱 | 5 | 約 15 g |
| S | 外殼套筒：左右側板、前板、後板 | 4 | 約 52 g |
| H | 頭：底板、3 片裙邊、四面牆、2 片 ESP32 卡板、眼圈 ×2、瞳孔、眼瞼 ×2、上蓋、定位板 | 17 | 約 44 g |

30 × 45 cm 板一台 2 張；**3 台一起排 5 張**（利用率約 79 %），營隊 10 台＝3 組＋1 台＝17 張。雷切＋雕刻一台約 30 分鐘（40 W 粗估）。
每片的編號、尺寸、在哪一張見 `laser/parts.csv`；改參數後在網頁「雷切」分頁重新下載。

### 12.2 採購件

JGA25-370 6 V（含霍爾編碼器）×2、GOOUUU ESP32-S3-CAM ×1、MAX98357A ×1、INMP441 ×1、DRV8870 雙路模組 ×1、SG92R ×1、
CH224K PD 誘騙板（設 9 V）×1、Mini560 5 V 降壓 ×1、AMS1117-3.3 模組 ×1、C-to-C 短線 10–15 cm（支援 PD 3 A）×1、喇叭（4 Ω／8 Ω 3 W）、KCD1 船型開關。
行動電源由學員自備（PD 20 W 以上、有 C 孔）。

### 12.3 電子小零件與五金

1000 µF／25 V ×1（C1）、SS34、470 µF／16 V ×2、100 kΩ＋33 kΩ、**1 kΩ ×4**、100 nF、JST-XH 6P／**8P** 各一組、5 × 7 洞洞板、20 mm 背對背魔鬼氈約 50 cm、
M3×6 圓頭（ISO 7380）×4（馬達）、M3×12＋M3 螺帽 ×4（上身→側壁 T 型槽）、M3×8＋M3 螺帽 ×4（外殼→側翼）、M3×10＋螺帽＋5 mm 尼龍隔離柱 ×4（DRV8870）、
M2×6 自攻 ×4（伺服耳片、舵盤）、M2×8＋螺帽 ×2（功放）、M4×40＋防鬆螺帽 ×2（惰輪軸，看套件）、杜邦母母線 20 cm ×24、20／22／24／26 AWG 矽膠線、熱縮管、3 mm 束線帶、螺旋纏線管。

木工：白膠（樹脂膠）、快乾膠（螺帽）、240／400 號砂紙、紙膠帶或橡皮筋、蠟燭一小截（頸部潤滑）、泡棉雙面膠。

---

## 13. 組裝步驟

網頁「組裝」分頁有 16 步動畫；哪裡上膠、哪裡不要上膠見 [`LASER.md`](LASER.md) 第 5 節。重點：

1. **雷切、清點、乾配底盤箱**：先切測試片校正，再切正式板。每個組件都先乾配，對了再上膠。
2. **裝馬達（對角）**：左馬達靠車尾、右馬達靠車頭；M3×6 圓頭從側壁外面鎖；尾端托柱＋束線帶。
3. **裝驅動輪與惰輪（套件）**：孔不合就用聯軸器；惰輪 M4 放進長槽先不鎖緊。
4. **DRV8870 與 C1**：5 mm 尼龍柱、端子朝車身中央、VM 在後。**可變電阻轉到最小、VO 不接**。
5. **電源區與 J1/J2**：⚠ **CH224K 先單獨接行動電源量到 9.0 V**；模組照底板的雷雕框貼。
6. **拼履帶**：惰輪往外推到「手指壓下去約 5 mm」，鎖緊 M4。
7. **托盤**：線壓低整理好，托盤前端插進前壁、後端放下，不上膠；魔鬼氈穿過長孔。
8. **上身骨架與功放**：脊板、側翼黏在上身底板；側翼壓入 M3 螺帽。
9. **配電板**：束線帶綁在右翼。
10. **頂板**：軸環、限位柱黏好；伺服先轉 90° 再裝；開關壓入；試轉頭沒問題再把頂板黏上骨架。
11. **頭部底盤**：三片裙邊黏好、磨順、抹蠟；舵盤鎖上、朝正前方套上花鍵。
12. **ESP32、麥克風、頭殼**：PCB 先塞進兩片卡板再插上底板；四面牆上膠；相機挪到右眼後面；眼睛黏上。
13. **頸部線束與上蓋**：手動轉頭 ±45° 確認線束沒有被拉緊；上蓋卡上去。
14. **上身合體、套外殼**：J1、J2 插好，4 顆 M3×12 鎖 T 型槽；外殼套筒從頭上往下套，4 顆 M3×8。
15. **放進行動電源**：推到底（短的先放墊塊）、C 孔朝後、魔鬼氈綁緊、接 C-to-C。
16. **通電測試**（`firmware/ares1_bringup`，用 TTL 口燒錄）：先量不短路 → 9 V → 5 V／3.3 V → 伺服 → 馬達 → 編碼器 → 喇叭 → 麥克風 → 地面測試。

---

## 14. 之後可以延伸的

- **任務模組**：前壁 2 × M3（間距 40）＋底板前緣 2 × M3（間距 60）已預留，網頁可開「推土板預覽」。
- **編碼器 B 相與 PCNT**：接上 GPIO3/46 後改用 ESP32-S3 的 PCNT 硬體計數，得到正反轉方向。
- **副版本：低重心履帶車**：同一個底盤箱＋電池艙，身體降到 40 mm、頭裝在前緣。參數化模型改 `bodyH`、`neckZ` 就能開始，雷切檔會跟著重排。
- **電量顯示**：PD 行動電源的 9 V 不會隨電量下降，想在 App 上看電量要另外接行動電源的 I2C（多數不支援），目前以行動電源本身的燈為準。

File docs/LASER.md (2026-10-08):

# ARES-1 雷切與組裝指南（3 mm 椴木合板）

> 一句話：整台車是 **46 片 3 mm 椴木合板**，榫頭插榫孔＋白膠，**零 3D 列印**。
> 30 × 45 cm 的板子切 **2 張**就夠一台；**3 台一起排只要 5 張**。雷射一台大約 **30 分鐘**。
> 履帶和輪子用廠商套件，木板只負責「箱子」。

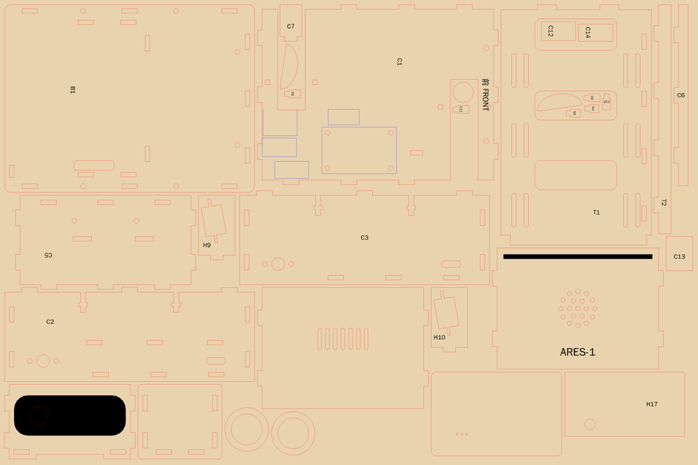
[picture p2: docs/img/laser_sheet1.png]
雷切排版：30 × 45 cm 第 1 張（小零件塞在托盤的大窗和底板的缺口裡）


---

## 0. 為什麼改成雷切

| | 3D 列印（舊版） | 雷切合板（現在） |
|---|---|---|
| 材料 | PLA／PETG 約 370 g（約 1/3 卷） | 3 mm 椴木合板 30 × 45 cm × 2 張（3 台一起 5 張） |
| 機器時間／台 | 一台車要印十幾到二十幾小時（估） | 雷切＋雕刻約 30 分鐘（40 W 粗估） |
| 10 台營隊 | 一台印表機要印一週以上 | 一個下午切完 |
| 印壞／切壞 | 大件印到一半失敗，整件重來 | 只重切那一片，幾十秒 |
| 改設計 | 改 CAD → 重切片 → 重印好幾小時 | 網頁改參數 → 下載 → 重切 |
| 重量 | 結構件約 350 g | 結構件約 260 g（車子輕了約 90 g） |

價格請以你們的實際報價為準：合板一張大約幾十元；學校雷切機通常只算時間或免費。
真正省的是**機器時間**：列印是「一台車一整天」，雷切是「一台車一節課」。

---

## 1. 檔案在哪裡

| 檔案 | 用途 |
|---|---|
| `laser/ARES1_test.svg`／`.dxf` | **切縫測試片**，每換一批板子先切這個（約 12 × 4 cm） |
| `laser/ARES1_450x300_sheet1of2.svg`、`sheet2of2` | 30 × 45 cm 板子，**一台 2 張** |
| `laser/ARES1x3_450x300_sheet1of5.svg` … `sheet5of5` | 30 × 45 cm 板子，**3 台一起排 5 張**（最省） |
| `laser/parts.csv` | 零件編號、名稱、尺寸、在哪一張 |
| 網頁「雷切」分頁 | 改板厚、切縫、板材大小、一次排幾台、名牌文字後**即時重新排版**，一鍵下載 zip（SVG＋DXF＋零件清單） |

`laser/` 裡的檔案是**預設參數**（板厚 3.00、切縫 0.15、間隙 0.05）。量完測試片數字不一樣的話，請用網頁重新下載。
想用指令重產：`node laser/export.mjs ply=2.9 kerf=0.18`（需要 Node＋Playwright）。

### 板材怎麼買、怎麼排最省

一台車的零件面積加起來大約是一張 30 × 45 的 **1.4 倍**，所以一台最少就是 2 張。要省，就讓幾台車**一起排**：

| 一次排幾台 | 30 × 45 張數 | 平均每台 | 利用率 |
|---|---|---|---|
| 1 台 | 2 張 | 2 張 | 約 66 %（第 2 張下面空一整條，約 45 × 9 cm，可以切測試片或備用零件） |
| 2 台 | 4 張 | 2 張 | 沒有比較省 |
| **3 台** | **5 張** | **1.67 張** | **約 79 %** |

**營隊建議：每 3 台一組切 5 張**，10 台就是 3 組＋1 台＝17 張（一台一台切要 20 張）。再多買 1–2 張切測試片、切壞備用。

排版用的是「真實形狀」：小零件（托柱、墊片、眼瞼、限位柱）會塞進托盤的大窗、底板的馬達缺口、軸環的圓洞裡。
塞在別片孔裡的零件，檔案裡排在前面先切（孔一切開，裡面那塊就掉下去了）。零件之間留 1.5 mm、板邊留 3 mm。

也可以「一張大＋一張小」：網頁「雷切 → 最後一張換成小板」選 38 × 27（8K），一台＝一張 30 × 45＋一張 38 × 27 也放得下。
不過 3 台一組 5 張平均起來更省，而且只要買一種板子。

### 顏色＝圖層

| 顏色 | 做什麼 | 圖層名 |
|---|---|---|
| 紅 `#FF0000` | 切穿 | CUT |
| 藍 `#0000FF` | 淺淺劃一條線（模組擺放位置、軸環對位圓） | SCORE |
| 黑 `#000000` | 填滿雕刻（零件編號、名牌、護目鏡、文字） | ENGRAVE |

- 單位 mm、原點在左上角，**檔案沒有畫板子外框**（不會多切一刀）。
- **切縫補償已經做在檔案裡**：外框往外 0.075、孔往內 0.075。雷切軟體裡的「切縫補償／offset」**不要再開**。
- 文字已經轉成外框，沒有字型問題，中文也可以。
- 每片零件「先切內孔、再切外框」排在檔案裡；LightBurn 再勾「Cut inner shapes first」更保險。

---

## 2. 先切測試片（10 分鐘，省下一整張板子）

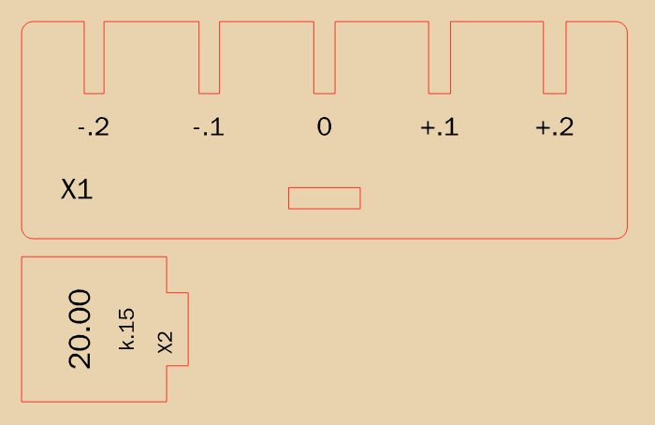
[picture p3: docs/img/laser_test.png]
切縫測試片


`ARES1_test.svg` 有兩片：

- **X1 板厚測試梳**：上面 5 個開口，寬度是「板厚＋2 × 間隙」再加減 0.2／0.1／0／+0.1／+0.2。下方有一個榫孔。
- **X2 20 mm 量規**：一個 20.00 mm 的方塊，下面帶一個榫頭（跟車上的榫頭一樣大）。

步驟：

1. **量板厚**：游標卡尺量你的板子 3 個地方，取平均。「3 mm」合板實際常是 2.7–3.2。
2. **量切縫**：切完 X2，量方塊的寬度。
   **真正的切縫 ＝ 檔案的切縫 ＋ 20 − 量到的寬**。例如設 0.15、量到 19.90 → 真正是 0.25。
3. **試間隙**：拿 X2 的邊插 X1 的 5 個開口，找「用手壓得進去、不會晃」那一格。
   - `0` 那格剛好 → 不用改。
   - `+0.1` 那格才剛好 → 間隙加 0.05；`−0.1` 那格剛好 → 間隙減 0.05。
4. **試榫頭**：X2 的榫頭插 X1 的榫孔，要能用手指壓進去。
5. 把板厚、切縫、間隙填進網頁「雷切」分頁 → 重新下載 → 再切一次測試片確認 → 切正式板。

> 同一家店不同批的板子厚度也會差 0.1–0.2 mm。**換一批板子就再切一次測試片。**

---

## 3. 雷切機設定（參考值，一定要先試）

每台機器、每批板子都不一樣，下面只是起點：

| 圖層 | 40 W CO2（參考） | 10 W 二極體雷射（參考） |
|---|---|---|
| 紅 切穿 | 速度 10–15 mm/s、功率 60–75 %、1 次，開氣泵 | 速度 3–5 mm/s、100 %、2–3 次 |
| 藍 劃線 | 速度 80–150 mm/s、功率 10–18 % | 速度 30–50 mm/s、30–40 % |
| 黑 雕刻 | 速度 200–300 mm/s、功率 15–25 %、線距 0.1 | 速度 80–120 mm/s、40–60 %、線距 0.1 |

- 順序：**雕刻 → 劃線 → 切割**（零件掉下去之前先雕好）。
- 板子要平：用蜂巢台＋磁鐵或大頭針壓四角；翹的板子切不穿。
- 焦距對在板子表面；切不穿寧可多切一次，不要把功率開到最大燒出一大片黑邊。
- ⚠ 雷切一定要有人顧著，旁邊放滅火器；氣泵一定要開。

---

## 4. 切完之後

1. **認零件**：結構件都雕了編號，字母代表它屬於哪一組：

   | 字頭 | 組件 | 片數 |
   |---|---|---|
   | C | 底盤箱（底板、左右側壁、前後壁、托盤凸緣、小立板、4 根托柱、3 片電源墊片） | 14 |
   | T | 電池艙托盤（托盤、右緣立板） | 2 |
   | B | 上身骨架（底板、脊板、兩片側翼） | 4 |
   | N | 頂板／頸座（頂板、兩片軸環、兩根限位柱） | 5 |
   | S | 身體外殼（左右側板、前板、後板） | 4 |
   | H | 頭（底板、三片裙邊、四面牆、兩片 ESP32 卡板、眼圈×2、瞳孔、眼瞼×2、上蓋、定位板） | 17 |
   | X | 測試片 | 2 |

   外殼、頭殼、眼睛、頂板這些「看得到的面」**不雕編號**（不想讓車子身上有一堆代號），靠形狀認，對照 `parts.csv` 或網頁「雷切 → 零件清單」。
2. **有雕刻／劃線的那一面＝模型上看得到雕刻的那一面**。檔案已經幫你翻好面，所以有些零件從雷切機上拿起來會跟模型左右相反，翻過來就對了。
3. 焦黑邊用 240 號砂紙**輕輕**刷一下就好，**榫頭不要磨**（會變鬆）。

---

## 5. 組裝：哪裡上膠、哪裡不要

**一律先乾配**（不上膠組一次），全部對了再拆開上膠。白膠薄薄一層，用紙膠帶或橡皮筋綁緊，**30 分鐘可以動、隔夜全乾**。溢出來的膠用濕布馬上擦掉。

| 組件 | 上膠 | 不上膠（要能拆） |
|---|---|---|
| 底盤箱 C | 底板、四面牆、托柱、托盤凸緣、托盤小立板、電源墊片 | — |
| 托盤 T | 右緣立板黏在托盤上 | **托盤本身**：前端榫頭插進前壁、後端落在後壁開口，抬起來就拿出來 |
| 上身骨架 B | 脊板、兩片側翼黏在上身底板上；側翼的 M3 螺帽點快乾 | 上身底板用 4 顆 M3×12 鎖在底盤側壁的 T 型槽 |
| 頂板 N | 兩片軸環照雷雕的圓圈疊黏；兩根限位柱 | **頂板最後才黏**到骨架上：伺服、開關裝好、頭試轉過再黏 |
| 外殼 S | 四片黏成套筒（側板在外、前後板在內） | 套筒用 4 顆 M3×8 鎖在側翼的螺帽上 |
| 頭 H | 三片裙邊照雷雕圓圈黏在頭部底板下面；四面牆；眼圈、瞳孔、眼瞼；上蓋＋定位板互黏 | **上蓋**直接卡進四面牆，不黏 |

小技巧：

- **外殼套筒怎麼黏才會正**：把頂板放在套筒上口當直角治具，四片夾著它一起乾。
- **ESP32**：先把 PCB 兩端塞進兩片卡板的十字孔，三個一起插進頭部底板，再裝四面牆。
- **T 型槽**：M3 螺帽從側壁的橫槽塞進去（螺帽會凸出側壁兩面一點點，正常），螺絲從上身底板鎖下來咬住它。
- **頸部轉動**：軸環和裙邊都用 400 號砂紙把接觸面磨順，抹一點蠟燭的蠟，轉起來就很順。
- 電路、馬達的安裝順序照網頁「組裝」分頁的 16 個步驟。

---

## 6. 板厚、切縫、間隙在模型裡做了什麼

- **板厚**：所有板件、榫頭深度、榫孔寬度、整台車的尺寸都由它算出來。網頁改板厚，3D 模型、檢查、雷切檔一起變。
- **切縫**：只影響雷切檔（外框往外、孔往內各偏一半），不影響模型。
- **間隙**：每個榫孔四邊各放大這個數字。0.05 是「手壓得進、上膠剛好」。

榫孔不是一個一個畫的：程式找出每個榫頭穿過哪一片板，就在那片板上挖孔。所以改尺寸不會有對不上的孔，
網頁「檢查 → 製造」會再確認一次：每個榫頭都有榫孔、孔不會破邊、孔跟孔不會黏在一起（不到 0.8 mm 會被燒斷）。

---

## 7. 常見問題

**榫頭插不進去？** 先確認板厚有照實測填；還是太緊就把「間隙」加 0.05 重切，或用砂紙磨**榫孔**（不是磨榫頭）。

**太鬆？** 有上膠的地方白膠會填滿，沒關係；不上膠的地方（托盤、上蓋）在邊上貼一圈紙膠帶。

**我們只有 30 × 20 的小雷切機？** 網頁「雷切」分頁選 30 × 20，一台 5 張；任何板子大小都能填進去重新排。

**可以用壓克力嗎？** 眼圈用 3 mm 橘色壓克力切很好看（同一個檔案）。整台用壓克力不建議：重量變兩倍（密度 1.19 vs 0.55）、榫頭容易裂、要用壓克力膠。

**可以用 3 mm MDF？** 可以，比較重（約 0.75）、比較便宜、邊比較黑。一樣先切測試片。

**我想讓學員設計自己的外觀？** 網頁「雷切」分頁可以改外殼左側的名牌（中文也可以）；「參數 → 表情眼瞼角度」可以改眼瞼。外殼四片上膠前可以先上色（壓克力顏料或水性漆，榫頭不要塗）。

---

## 8. 3D 列印版還在嗎？

`cad/`（OpenSCAD＋STL）和 [`PRINTING.md`](PRINTING.md) 保留當**備案**，但它是改木板之前的幾何（立柱＋熱熔螺母、列印履帶），
跟現在的木板版尺寸不完全一樣。**以網頁和 `laser/` 為準。**

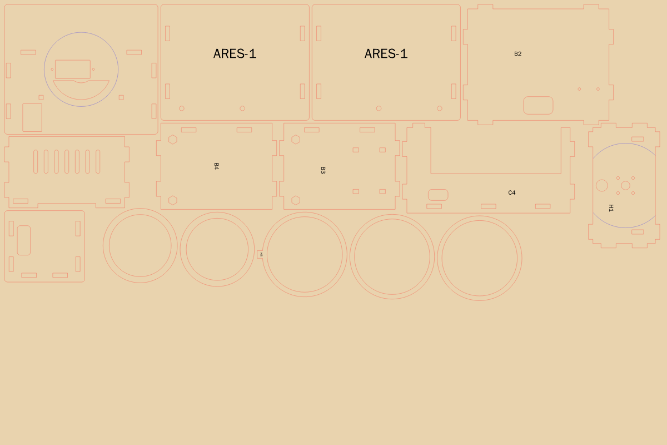
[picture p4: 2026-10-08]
docs/img/laser_sheet2.png

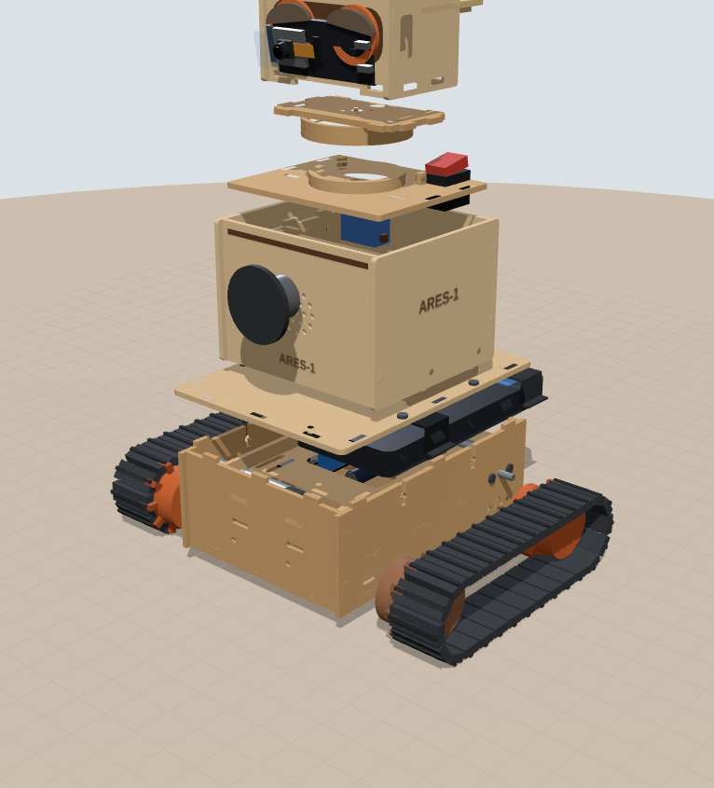
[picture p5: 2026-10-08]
docs/img/wood_exploded.png

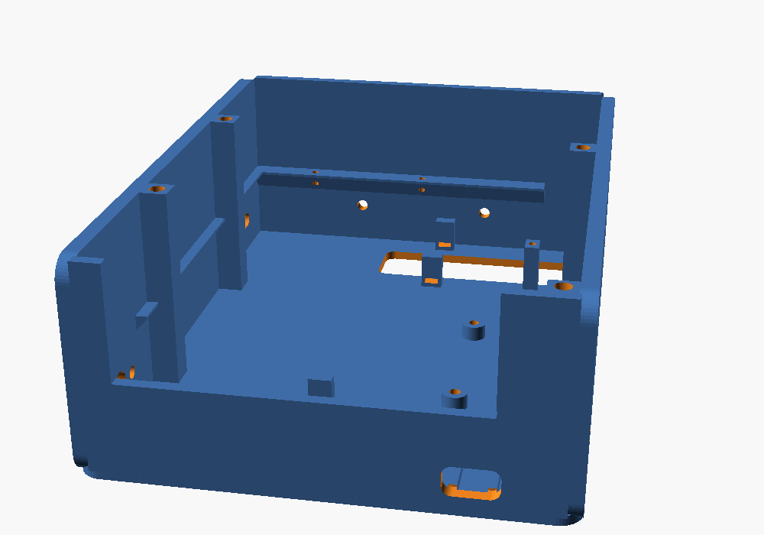
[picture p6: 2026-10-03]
docs/img/cad_tub_bay.png

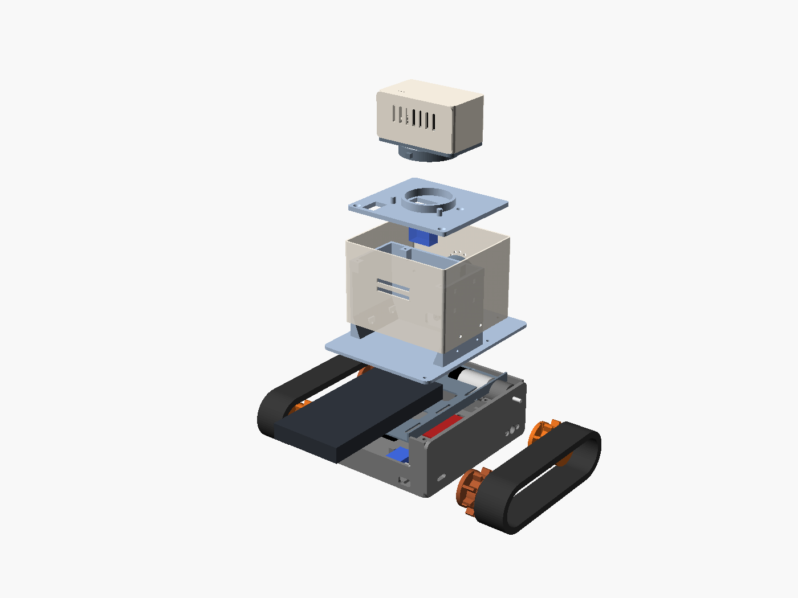
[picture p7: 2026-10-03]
docs/img/cad_exploded.png

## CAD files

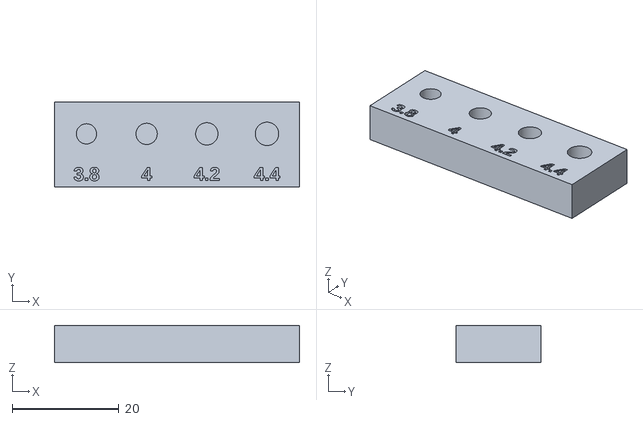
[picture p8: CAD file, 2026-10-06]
cad/stl/fit/fit_insert.stl
46.0 x 16.0 x 7.00

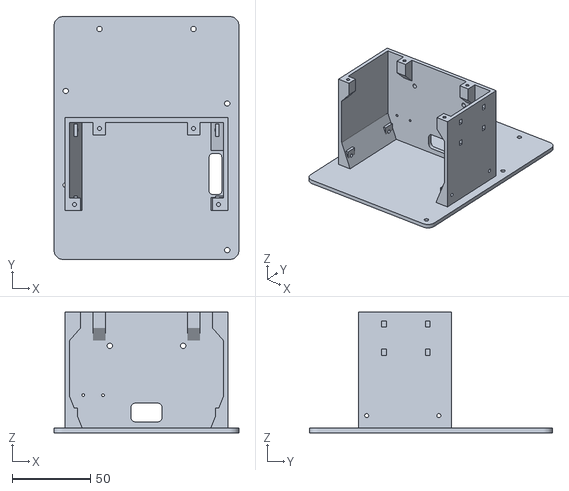
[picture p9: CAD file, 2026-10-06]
cad/stl/upper_frame.stl
118.0 x 155.0 x 77.0

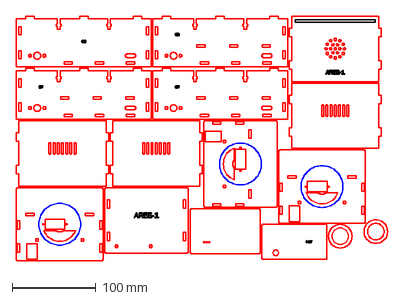
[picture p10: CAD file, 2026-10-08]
laser/ARES1x3_450x300_sheet3of5.dxf
443.6 x 292.6 mm

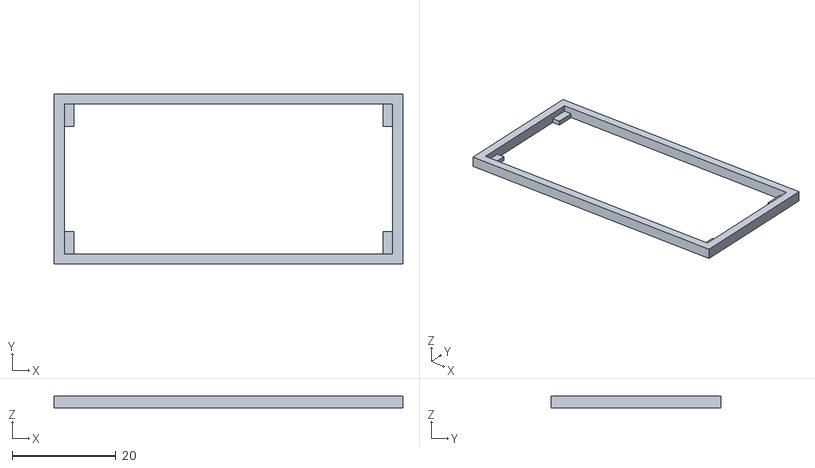
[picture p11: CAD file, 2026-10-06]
cad/stl/fit/fit_pcb.stl
67.4 x 32.9 x 2.40

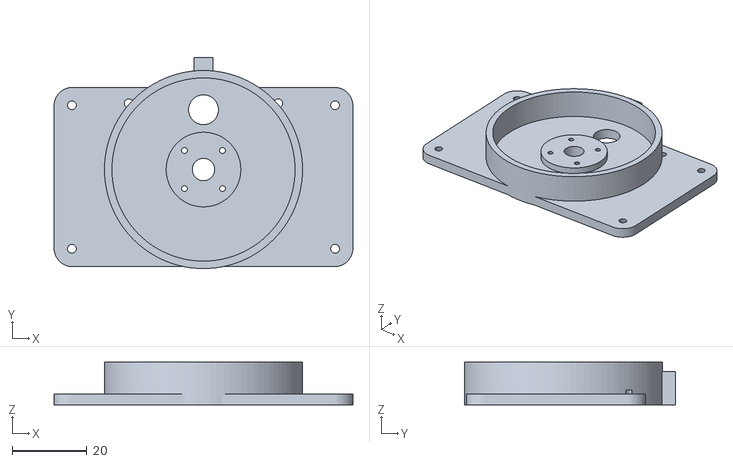
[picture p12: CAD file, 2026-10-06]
cad/stl/head_floor.stl
80.0 x 56.5 x 11.5

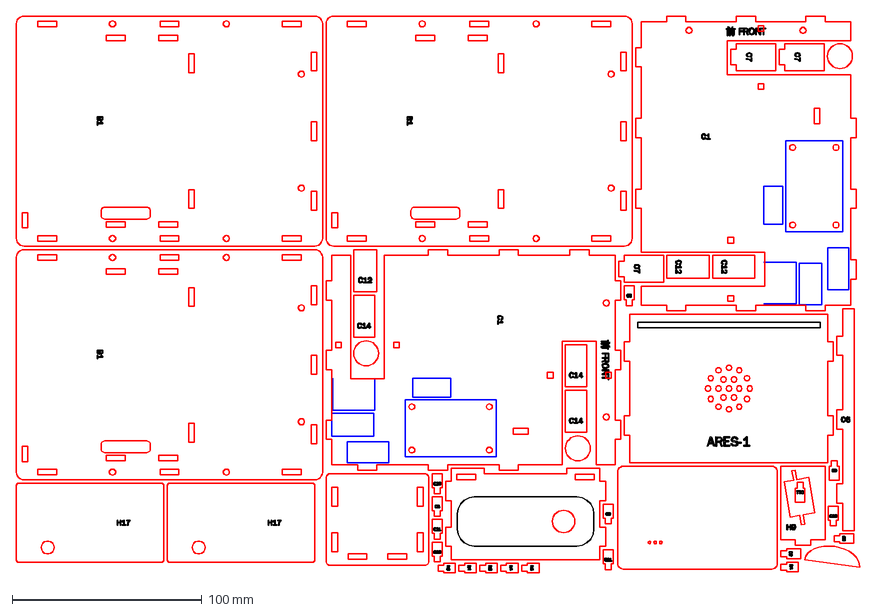
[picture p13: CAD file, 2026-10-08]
laser/ARES1x3_450x300_sheet1of5.dxf
443.9 x 293.1 mm

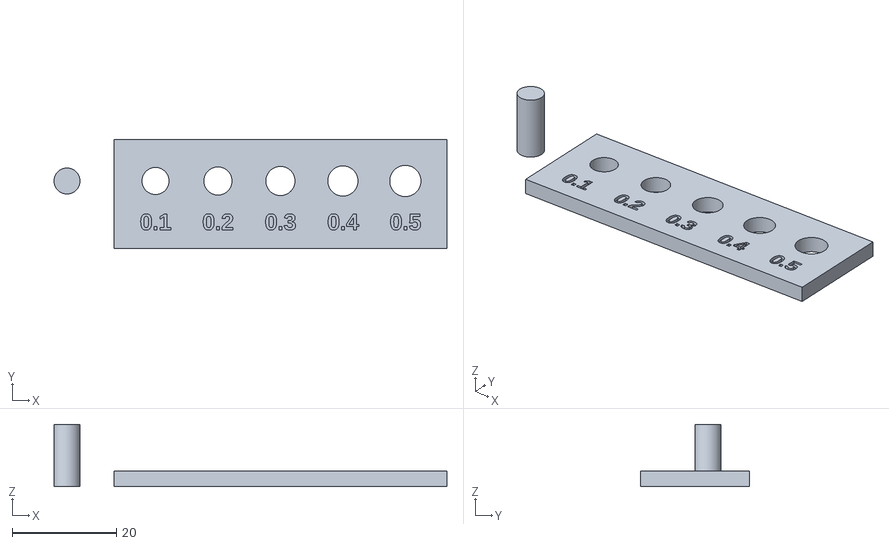
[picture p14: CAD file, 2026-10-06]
cad/stl/fit/fit_tol.stl
75.5 x 21.0 x 12.0

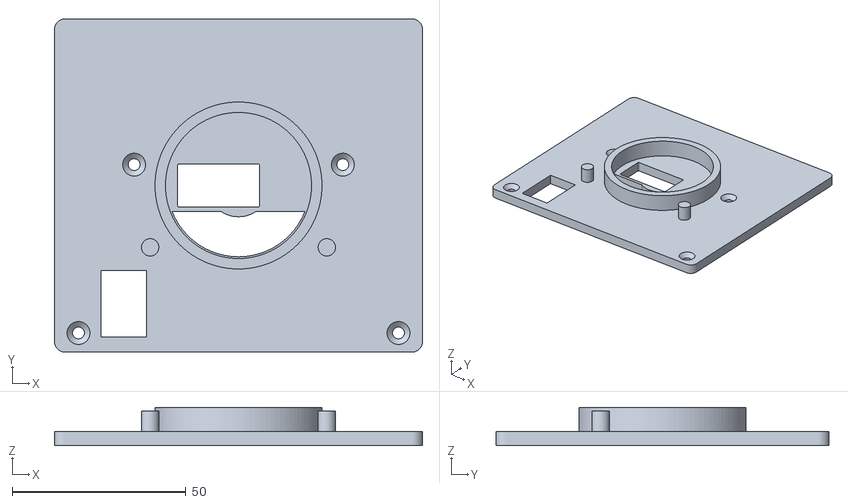
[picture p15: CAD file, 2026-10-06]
cad/stl/neck_deck.stl
105.8 x 95.8 x 11.0

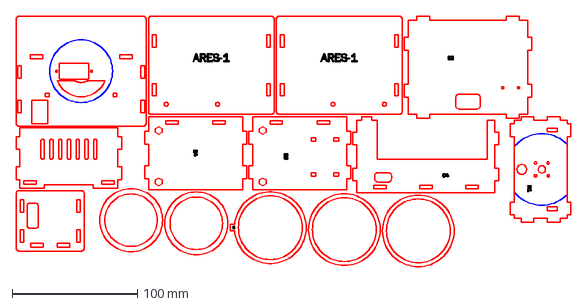
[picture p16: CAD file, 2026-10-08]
laser/ARES1_450x300_sheet2of2.dxf
442.1 x 199.7 mm

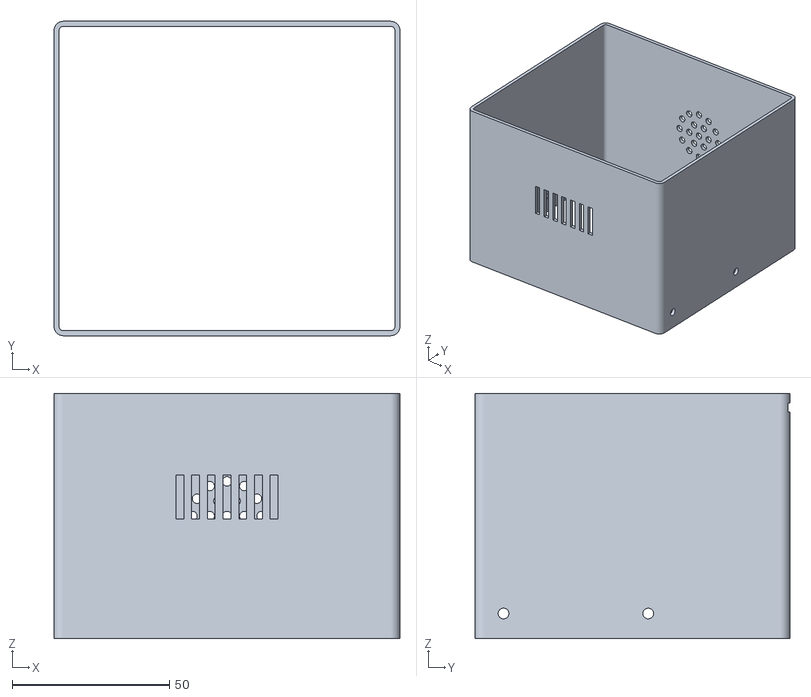
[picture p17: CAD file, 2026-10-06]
cad/stl/body_shell.stl
110.0 x 100.0 x 78.0

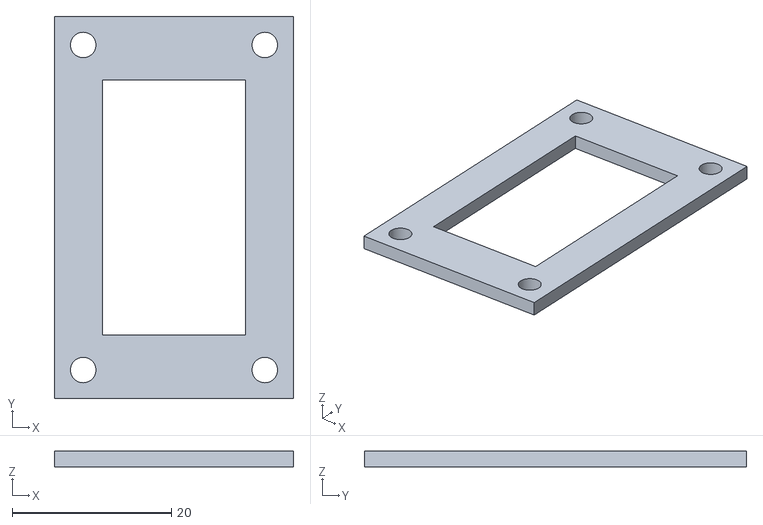
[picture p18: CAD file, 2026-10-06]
cad/stl/fit/fit_drv.stl
30.0 x 48.0 x 2.00

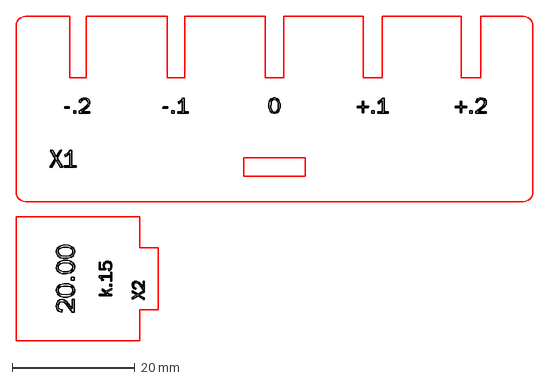
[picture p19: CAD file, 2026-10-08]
laser/ARES1_test.dxf
84.2 x 52.8 mm

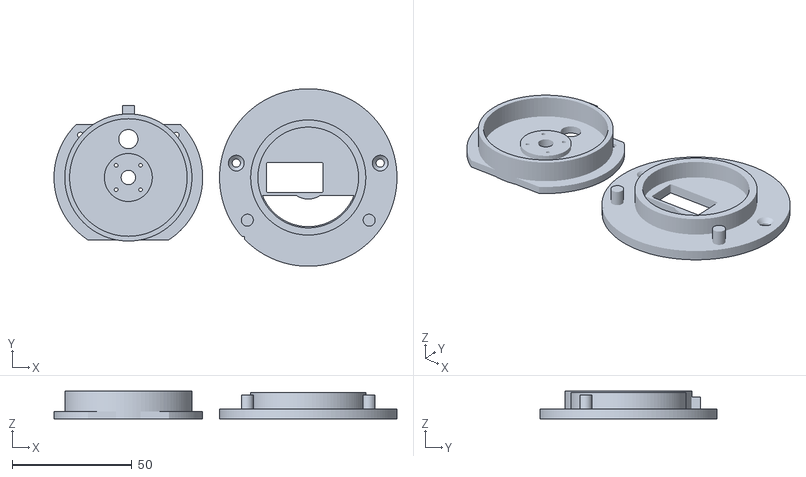
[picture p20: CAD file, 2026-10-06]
cad/stl/fit/fit_neck.stl
143.0 x 74.0 x 11.5

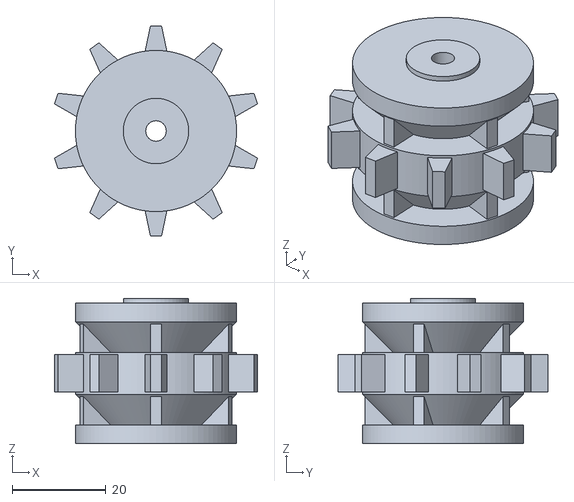
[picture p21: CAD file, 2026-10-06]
cad/stl/idler.stl
43.4 x 44.9 x 31.0

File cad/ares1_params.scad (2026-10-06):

// =====================================================================
// ARES-1 參數檔（單位 mm）
// 名稱與 web/index.html 的 DEFAULTS 完全相同，網頁「參數 → 產生 OpenSCAD 參數」
// 輸出的內容可以直接貼進來取代。
//
// 狀態標記： [C] 已確認（使用者提供）  [E] 估計  [M] 待量測  [D] 設計值
// =====================================================================

layout = "B";          // [D] "B" 對角馬達（主方案）/ "A" 同軸後置 / "C" 長頸桅杆
mic_in_head = true;    // [D] INMP441 放頭部（推薦）

// ---------- 底盤與履帶 ----------
innerW        = 110;   // [D] 兩側壁內面距離
wheelbase     = 111.5; // [D] 驅動輪↔惰輪中心距（配合 28 片履帶）
trackW        = 30;    // [D] 履帶寬
trackPitch    = 12.5;  // [D] 履帶節距
sprocketTeeth = 10;    // [D] 鏈輪齒數 → 節圓 40.45 ≈ Ø41 [E]
plateT        = 4;     // [D] 側壁（兼馬達座）厚
trackGap      = 1.5;   // [D] 側壁外面到履帶內緣
trackT        = 5;     // [D] 履帶片厚（插銷處）
grouser       = 1.5;   // [D] 抓地齒高
floorY        = 12;    // [D] 底板下緣離地
floorT        = 2.5;   // [D] 底板厚

// ---------- JGA25-370（6 V 版） ----------
motorD    = 25;        // [C] 本體直徑
motorCan  = 31;        // [C] 馬達段
encLen    = 11;        // [C] 編碼器蓋
gearLen   = 22;        // [E] 減速箱長 L（未標示）
shaftD    = 4;         // [C] 輸出軸
shaftLen  = 12.5;      // [C] 輸出軸突出
motorHole = 17;        // [C] 前端 2×M3 中心距

// ---------- 行動電源（學員自備）與電池艙 ----------
bankMount  = "deck";   // [D] "deck" 放電池艙（主方案）/ "back" 掛身體背後（比較用，不建議）
bankL      = 148;      // [M] 行動電源長（預設＝10000 mAh 薄型）
bankW      = 70;       // [M] 寬（電池艙可用 85）
bankT      = 15;       // [M] 厚（≤ bayH − 0.5）
bankSpacer = 0;        // [D] 前方墊塊總長（短的行動電源用）
bayH       = 28;       // [D] 電池艙高度（托盤頂面到上身底板）

// ---------- 模組 ----------
drvL = 48;  drvW = 30;               // [C] DRV8870 雙路模組 PCB
buckL = 22; buckW = 17; buckH = 6;   // [E] Mini560 5 V 降壓模組（在底盤電源區）
spkD = 40;  spkH = 20;               // [E] 喇叭

// ---------- 身體 ----------
bodyW  = 110;          // [D]
bodyD  = 100;          // [D]
bodyH  = 78;           // [D] 電池艙把底盤墊高，身體縮短讓總高不變
shellT = 1.6;          // [D] 外殼壁厚（0.4 噴嘴 4 圈）
deckT  = 3;            // [D] 上身底板厚

// ---------- 頭部 ----------
neckExtra  = 0;        // [D] 頸部加高（方案 C 用 70）
neckZ      = 0;        // [D] 轉軸前後位置
headZ      = 2;        // [D] 頭部中心相對轉軸前移
headW      = 80;       // [D]
headH      = 44;       // [D]
headD      = 48;       // [D]
camTilt    = 10;       // [D] 鏡頭俯角（度）
lensOffset = -20;      // [M] 鏡頭偏離 PCB 中心（負＝天線端）。GOOUUU 相機貼在模組鐵殼上約 -20 → 真鏡頭在右眼
lensH      = 11;       // [M] 鏡頭前緣高出 PCB 正面（相機模組墊在鐵殼上）
eyelid     = 8;        // [D] 表情眼瞼角度（度）
yawMax     = 45;       // [D] 軟體轉頭範圍 ±

// ---------- 列印公差（先印試配套件 fit_*.stl 再決定） ----------
tol = 0.3;             // [M] 單邊配合間隙：fit_tol 上「銷剛好能順順插進去」的那個孔＝你的印表機值
insertD = 4.0;         // [M] M3 熱熔螺母孔徑：看 fit_insert 哪個孔燙進去最正（依螺母品牌不同）
idler_bearing = false; // [D] true = 惰輪壓 624ZZ 軸承；false = 直接套 M4 螺絲

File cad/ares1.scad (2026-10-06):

// =====================================================================
// ARES-1 直立式雙履帶火星探測車 — 參數化零件庫
//
// 用法：
//   openscad -D 'part="tub"' -o stl/tub.stl ares1.scad
//   part = "assembly" 會顯示整車組合（含簡化的電子零件，不可列印）
//
// 座標（組合狀態）：建模時 x = 車子左側、y = 車頭方向、z = 向上，原點在地面中心，
// 與 web/index.html 對應 web(X, Y, Z) = scad(x, z, y)。這個對應是鏡像，輸出前由 out() 鏡射回來。
// 每個零件用 print_*() 轉成列印方向（平放在 z = 0）。
// =====================================================================
include <ares1_params.scad>

part = "assembly";   // 由命令列 -D 覆寫
yaw  = 0;            // 組合預覽時的頭部角度
explode = 0;         // 組合預覽的爆炸量（0–1）
$fn = 48;

// ------------------------- 衍生尺寸（與網頁 computeLayout 相同） -------------------------
PD      = trackPitch / sin(180 / sprocketTeeth);
Rp      = PD / 2;
pinY    = grouser + trackT / 2;
axleY   = pinY + Rp;
trackTop= axleY + Rp + trackT / 2 + grouser;
hw      = innerW / 2;
wallOut = hw + plateT;
trackX0 = wallOut + trackGap;
trackCx = trackX0 + trackW / 2;
trackOut= trackX0 + trackW;
zS      = wheelbase / 2;
loopLen = 2 * wheelbase + PI * PD;
links   = round(loopLen / trackPitch);
motorTotal = gearLen + motorCan + encLen;
mR      = motorD / 2;
floorTop= floorY + floorT;
tubLen  = ceil(wheelbase + motorD + 18);
tubZ0   = -tubLen / 2;
tubZ1   = tubLen / 2;
endWallT= 3;
// 底盤是「雙層巴士」：下層馬達＋驅動板＋電源區，上層整層是行動電源的電池艙
bay     = (bankMount != "back");
trayY0  = axleY + mR + 0.8;          // 托盤底面＝馬達頂 +0.8
trayT   = 1.6;
trayTop = trayY0 + trayT;
deckY0  = bay ? trayTop + bayH : max(trackTop + 0.6, trayY0);
deckY1  = deckY0 + deckT;
coax    = (layout == "A");
mLz     = -zS;
mRz     = coax ? -zS : zS;
// 馬達：[sign, flangeX, z]
MOTORS  = [[+1, hw, mLz], [-1, -hw, mRz]];
// 右側線材通道（地板直通上身）、托盤右緣立邊、電池艙
chX0 = -hw; chX1 = -hw + 16;
lipX0 = chX1; lipX1 = chX1 + 2;
pillarW = 7;
bayX0 = lipX1; bayX1 = hw - pillarW;       // 可用寬（預設 85）
bayZ1 = tubZ1 - endWallT;                  // 前壁就是擋塊，後方整個打開
// 上身固定立柱 [x0, x1, y0, y1]（頂端 M3 熱熔螺母）
PILLARS = [[hw - pillarW, hw, -33.5, -26.5], [hw - pillarW, hw, 26.5, 33.5],
           [-hw, -hw + pillarW, 18.5, 25.5], [-hw, -hw + pillarW, tubZ0 + endWallT, tubZ0 + endWallT + 6]];
TRAYPOST = [lipX0 - 2, lipX1, 20, 26];
STRAP_SLOTS = [-55, -10, 35];
SLOT_X = [lipX1 + 2.5, lipX1 + 10.5, bayX1 - 10.5, bayX1 - 2.5];
TRAY_SCREWS = [[0, tubZ1 - endWallT - 3], [35, tubZ1 - endWallT - 3], [(TRAYPOST[0] + TRAYPOST[1]) / 2, (TRAYPOST[2] + TRAYPOST[3]) / 2]];
// 驅動板：右側，端子朝車身中央、VM 在後端，排針在線材通道正下方
drvX    = -(hw - 4 - drvW / 2);
drvZ    = -12;
DRV_HOLE = [11.4, 20.4];   // 孔距 22.8 × 40.8（由 R3.6 圓角推得）
// 電源區（下層右後角；同軸方案改右前）：CH224K、Mini560、AMS1117
pwS  = coax ? -1 : 1;
pwZi = coax ? tubZ1 - endWallT : tubZ0 + endWallT;
function pzr(a, b) = [min(pwZi + pwS * a, pwZi + pwS * b), max(pwZi + pwS * a, pwZi + pwS * b)];
PDB  = concat([-hw + 15, -hw + 27], pzr(-2.5, 22));           // [x0, x1, y0, y1]
BUCK = concat([-hw + 28.5, -hw + 28.5 + buckW], pzr(0.5, 0.5 + buckL));
LDO  = concat([-hw + 1, -hw + 12], pzr(8, 30));
modY0 = floorTop + 3;
usbX = -hw + 21;
usbY = modY0 + 3.2;
usbWallY = coax ? tubZ1 - endWallT : tubZ0;
deckHole = [chX0 + 7, chX1 - 1, -36, -10];   // [x0, x1, y0, y1]
bodyY0  = deckY1;
bodyY1  = bodyY0 + bodyH;
bw      = bodyW / 2;
inW     = bw - shellT;
inZ0    = -bodyD / 2 + shellT;
inZ1    = bodyD / 2 - shellT;
topT    = 4;
topY1   = bodyY1;
topY0   = topY1 - topT;
wingX1  = inW - 1.4;
wingX0  = wingX1 - 3;
spineZ0 = neckZ + 10;
spineZ1 = spineZ0 + 3;
spkZF   = inZ1 - 1;
spkZB   = spkZF - spkH;
spkY    = bodyY0 + min(max(bodyH * 0.5, 26), 52);
ampX    = min(max(spkD / 2 + 14, 20), wingX0 - 10);
ampY    = bodyY0 + 14;
swX     = bw - 22;
perfY0  = min(bodyY0 + 43, topY0 - 31);
swZ     = -bodyD / 2 + 16;
riserH  = neckExtra;
mountY1 = topY1 + riserH;
mountY0 = mountY1 - 4;
// SG92R（SG9x 規格書值，待實物量測）
// 23.2×12.1×22.7、跨距 32.1、總高 30.5 依商品圖 [C]；耳片高度、軸心位置 [E]
sv_l = 23.2; sv_w = 12.1; sv_h = 22.7; sv_tabSpan = 32.1; sv_tabT = 2.5; sv_tabZ = 15.9;
sv_shaftOff = 5.9; sv_bossD = 11.8; sv_bossH = 4.0; sv_holeSp = 27.8; sv_hornD = 20; sv_hornH = 4.2;
servoY0 = mountY0 - sv_tabT - sv_tabZ;
servoTop= servoY0 + sv_h;
bossTop = servoTop + sv_bossH;
hornTop = bossTop + sv_hornH;
pivotY  = hornTop + 2;
collarR0 = 21; collarR1 = 24; collarH = 7;
skirtR0 = collarR1 + tol + 0.2; skirtR1 = skirtR0 + 2; skirtDrop = 8.5;   // 預設 tol 0.3 → 裙邊 ID 49
harnessR = 16;
stopAng = yawMax + 10;
stopR   = 31;
winR0 = 9; winR1 = collarR0 - 0.5; winZ = -7.5;
// 頭部（區域座標：原點＝轉軸與頭部底面交點，y 朝前，z 朝上）
hW = headW / 2; hT = 1.8; hFloorT = 3;
hz0 = headZ - headD / 2;
hz1 = headZ + headD / 2;
lensFrontZ = hz1 - 1;
pcbY = headH / 2 + 1;
pcbFrontZ = lensFrontZ - lensH;
esp_l = 62.6; esp_w = 28.3; esp_t = 1.6;
camEye = abs(lensOffset) >= 12 ? sign(lensOffset) : 0;   // 真鏡頭在哪一隻眼（-1＝右眼）
eyeX = camEye != 0 ? abs(lensOffset) : min(hW - 18, 21);
micP = [esp_l / 2 - 9, hz0 + 12, headH - hT];
// 上身骨架的頂板螺絲柱
TOP_BOSSES = [[wingX0 - 3, inZ0 + 6], [-(wingX0 - 3), inZ0 + 6], [30, spineZ0 - 4], [-30, spineZ0 - 4]];
SHELL_SCREWS = [-41, 5];   // 外殼側面螺絲的 y 位置（z = bodyY0 + 8）；-41 避開右後方線孔

echo(str("ARES-1: PD=", PD, " axleY=", axleY, " links=", links, " tubLen=", tubLen, " trayY0=", trayY0, " deckY0=", deckY0, " pivotY=", pivotY));

// ------------------------- 小工具 -------------------------
module rr2(x0, y0, x1, y1, r) {
  rr = min(r, (x1 - x0) / 2 - 0.01, (y1 - y0) / 2 - 0.01);
  translate([x0 + rr, y0 + rr]) offset(r = rr) square([x1 - x0 - 2 * rr, y1 - y0 - 2 * rr]);
}
module plateYZ(x0, t) { translate([x0, 0, 0]) rotate([90, 0, 90]) linear_extrude(t) children(); }   // 2D(y,z) 沿 +x 擠出
module plateXZ(y0, t) { translate([0, y0 + t, 0]) rotate([90, 0, 0]) linear_extrude(t) children(); } // 2D(x,z) 沿 +y 擠出
module boxB(x0, x1, y0, y1, z0, z1) { translate([min(x0, x1), min(y0, y1), min(z0, z1)]) cube([abs(x1 - x0), abs(y1 - y0), abs(z1 - z0)]); }
module cylX(r, x0, x1, y, z) { translate([min(x0, x1), y, z]) rotate([0, 90, 0]) cylinder(r = r, h = abs(x1 - x0)); }
module cylY(r, y0, y1, x, z) { translate([x, min(y0, y1), z]) rotate([-90, 0, 0]) cylinder(r = r, h = abs(y1 - y0)); }
module ring(r0, r1, h) { difference() { cylinder(r = r1, h = h, $fn = 96); translate([0, 0, -1]) cylinder(r = r0, h = h + 2, $fn = 96); } }
function arcpts(r, a0, a1, n, cy) = [for (i = [0:n]) let(t = a0 + (a1 - a0) * i / n) [r * sin(t), cy - r * cos(t)]];
aOut = acos(-winZ / winR1);
aIn  = acos(-winZ / winR0);
WINDOW = concat(arcpts(winR1, -aOut, aOut, 24, neckZ), arcpts(winR0, aIn, -aIn, 12, neckZ));
// 頭部 PCB 座標（原點在 PCB 正面中心，y 為法線朝前）→ 頭部區域座標
function F2H(p) = [p[0], pcbFrontZ + p[1] * cos(camTilt) + p[2] * sin(camTilt), pcbY - p[1] * sin(camTilt) + p[2] * cos(camTilt)];
module inPCBFrame() { translate([0, pcbFrontZ, pcbY]) rotate([-camTilt, 0, 0]) children(); }
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

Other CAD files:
laser/ARES1x3_450x300_sheet4of5.dxf
cad/stl/fit/fit_motor.stl
cad/stl/head_hood.stl
laser/ARES1x3_450x300_sheet2of5.dxf
cad/stl/bank_spacer.stl
cad/stl/battery_tray.stl
cad/stl/eye_ring.stl
cad/stl/eyelid.stl
cad/stl/fit/fit_hub.stl
cad/stl/fit/fit_track.stl
cad/stl/head_back.stl
cad/stl/pupil.stl
cad/stl/speaker_ring.stl
cad/stl/sprocket.stl
cad/stl/track_link.stl
cad/stl/track_links_16.stl
cad/stl/tub.stl
laser/ARES1_400x300_sheet1of2.dxf
laser/ARES1_400x300_sheet2of2.dxf
laser/ARES1_450x300_sheet1of2.dxf
laser/ARES1x3_450x300_sheet5of5.dxf

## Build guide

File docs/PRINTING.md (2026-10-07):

# ARES-1 列印指南（備案）

> ⚠ **這份是備案。** 營隊已改用 3 mm 椴木合板雷切（便宜很多、一台約 30 分鐘），請看 [`LASER.md`](LASER.md)。
> 下面的 STL 是改木板之前的幾何，跟現在的木板版不完全一樣；真的要回頭用 3D 列印，請先告訴我，我把 CAD 同步到最新尺寸。

> 先花 1 小時印「試配套件」，拿真的馬達、伺服、ESP32、驅動板試過，再印大件。
> 大件（底盤槽、上身骨架）一件就要好幾個小時，印完才發現孔對不上最傷。

所有 STL 都已經擺好列印方向，**直接丟進切片軟體，不要縮放、不要旋轉**。
所有零件都設計成**免支撐**。

---

## 1. 一台車要印什麼

| 零件 | STL | 數量 | 材料 | 印之前要先確認 | 約略用量 |
|---|---|---|---|---|---|
| 底盤槽 | `stl/tub.stl` | 1 | PLA 或 PETG | **等履帶套件尺寸改好再印**；`fit_motor`、`fit_drv`、`fit_insert` 過關；量馬達總長 | 110 g |
| ~~驅動輪、惰輪、履帶片~~ | `sprocket`、`idler`、`track_links_16` | 0 | — | 用廠商的履帶套件，不用印（檔案留著當備案） | — |
| 電池艙托盤 | `stl/battery_tray.stl` | 1 | PLA | — | 15 g |
| 前方墊塊 | `stl/bank_spacer.stl` | 0–3 | PLA | 看學員行動電源長度（網頁「檢查」會算） | 每片 5 g |
| 上身骨架 | `stl/upper_frame.stl` | 1 | PLA | 確認喇叭型式 | 85 g |
| 頂板／頸座 | `stl/neck_deck.stl` | 1 | PETG | `fit_neck` 過關 | 30 g |
| 身體外殼 | `stl/body_shell.stl` | 1 | PLA | 確認喇叭型式（格柵位置） | 60 g |
| 喇叭墊高環 | `stl/speaker_ring.stl` | 1 | PLA | 確認喇叭型式 | 11 g |
| 頭部轉盤 | `stl/head_floor.stl` | 1 | PETG | `fit_neck` 過關 | 12 g |
| 頭罩 | `stl/head_hood.stl` | 1 | PETG | `fit_pcb` 過關；量好鏡頭位置 | 20 g |
| 頭部後蓋 | `stl/head_back.stl` | 1 | PETG | 跟頭罩一起印 | 7 g |
| 眼圈 | `stl/eye_ring.stl` | 2 | 橘色 PLA | — | 1 g |
| 瞳孔（造型眼） | `stl/pupil.stl` | 1 | 深灰 PLA | — | < 1 g |
| 眼瞼（可換表情） | `stl/eyelid.stl` | 2 | 任意顏色 | — | < 1 g |

一台車合計約 **370 g**（PLA 約 280 g、PETG 約 90 g）：1 kg 的 PLA 大約夠 3 台。
用量是由模型體積乘上填充率估的，實際以切片軟體為準。

### 輪子與履帶：用廠商的套件

營隊用廠商買的履帶和輪子，履帶是一節一節拼的，長度可以自己加減，所以 `sprocket`、`idler`、`track_links_16` 都不用印。

但**輪子的大小決定整個底盤的高度**：輪軸高度、馬達孔位置、惰輪槽、離地間隙、電池艙托盤高度都是從輪徑算出來的。
所以**底盤槽要等套件尺寸填進模型、重產 STL 之後才印**。其他零件（頭、頂板、托盤、外殼）不受影響，可以先印。

要量的東西（拍照＋卡尺）：

1. 驅動輪：外徑（含齒）、齒數、輪寬、中心孔的形狀和尺寸（圓孔／D 形孔／六角孔、幾 mm）、有沒有附固定螺絲或聯軸器。
2. 惰輪：外徑、輪寬、中心孔尺寸、有沒有軸承。
3. 履帶：節距（量 10 節的長度 ÷ 10 最準）、寬度、厚度、內側有沒有導齒。
4. 套件附的軸或螺絲規格。

驅動輪的孔如果不是 Ø4 D 形孔（JGA25-370 的軸），我會多做一個轉接輪轂讓它鎖上馬達軸。

---

## 2. 先印試配套件（`stl/fit/`，一盤約 1–1.5 小時、40 g）

每一片都是從正式零件直接裁下來、或用同一組尺寸做的，所以試配過了，正式件就配得起來。
除了 `fit_hub`、`fit_track`（用廠商履帶就不需要），其餘 6 個檔案拖進切片軟體，按「自動排列」一次印完。

| 試配片 | 拿什麼試 | 怎樣算過關 | 不過關怎麼辦 |
|---|---|---|---|
| `fit_tol` | 附的 Ø5 銷，輪流插 5 個孔 | 找出「用手推得進去、不會晃」的最小孔 | 孔旁的數字就是你印表機的 `tol`（預設 0.3） |
| `fit_insert` | 用烙鐵把 M3 熱熔螺母燙進 4 個孔 | 燙進去垂直、不鬆、旁邊沒有爆裂 | 那個孔的數字就是 `insertD`（預設 4.0） |
| `fit_motor` | JGA25-370 前端的銅套凸台插進中間孔，2 顆 M3×6 圓頭鎖上 | 凸台平貼，螺絲頭沉進沉孔不凸出 | 孔對不上：量馬達前端兩孔的中心距告訴我（目前 17 mm） |
| `fit_hub`、`fit_track` | 用廠商履帶套件就**不用印**這兩片 | — | — |
| `fit_neck` | 左片：SG92R 從下面塞進方孔；右片：裙邊套到左片的軸環上轉 | 伺服塞得進、耳片貼平；轉盤轉得順，轉到約 ±55° 被限位柱擋住 | 伺服塞不進或轉盤卡 → `tol` +0.1 |
| `fit_pcb` | ESP32-S3-CAM 平放進框裡 | 四角架在小台階上，四周有一點點空隙 | 放不進 → `tol` +0.1 |
| `fit_drv` | DRV8870 模組疊上去 | 4 個孔對齊 | 對不上：量孔距告訴我（目前 40.8 × 22.8 是推估值，最容易錯） |

改數字的方法：把結果告訴我，我幫你重產全部 STL；或自己改 `cad/ares1_params.scad` 的 `tol`、`insertD`，再執行 `cad/build_stl.sh`（要裝免費的 OpenSCAD）。

---

## 3. 列印順序

1. **第 0 批：試配套件**。全部過關才往下。
2. **第 1 批：不用等量測的**。托盤、頂板、頭部轉盤、眼睛。
3. **第 2 批：等實物確認的**。
   - 底盤槽：等履帶套件尺寸改進模型，加上 `fit_motor`、`fit_drv` 過關、量好馬達總長。
   - 頭罩＋後蓋：等鏡頭位置量好（鏡頭中心到天線端的距離、高出 PCB 多少）。
   - 上身骨架、外殼、喇叭墊高環：等喇叭確定是 Ø40 圓形還是長方形。
   - 前方墊塊：等學員帶來的行動電源。

---

## 4. 切片設定

| 項目 | 建議 |
|---|---|
| 層高 | 0.2 mm |
| 牆 | 3 圈（外殼 4 圈，模型就是照 1.6 mm 壁厚設計的） |
| 填充 | 20% 格狀 |
| 支撐 | 不用 |
| 第一層 | 開「象腳補償」0.15–0.2 mm。第一層外擴是印出來組不起來最常見的原因 |
| 孔洞補償 | 先不要開，間隙已經由 `tol` 處理 |
| PETG | 風扇 50% 以上，幫助橋接；頭罩、頂板、輪子用 PETG 比較耐熱、耐磨 |
| 頭罩 | 臉朝下印。護目鏡和眼圈座是 0.6／1.2 mm 的淺凹槽，會用橋接印出來，貼上黑色貼紙和眼圈就看不到 |

---

## 5. 印完先試裝

每印完一件就跟它的配合件試一次，不要等全部印完：

- 底盤槽：馬達鎖得上、DRV8870 螺絲座對得上、熱熔螺母燙得正。
- 托盤：放進底盤槽，四邊不卡，3 顆 M2.5 鎖得上。
- 上身骨架：疊在底盤槽上，4 個螺絲孔對準立柱。
- 頂板：放進外殼上口，四周不卡（外殼要能從上面套下來）。
- 頭罩：ESP32 放得進四個角座，鏡頭對得到右眼孔。

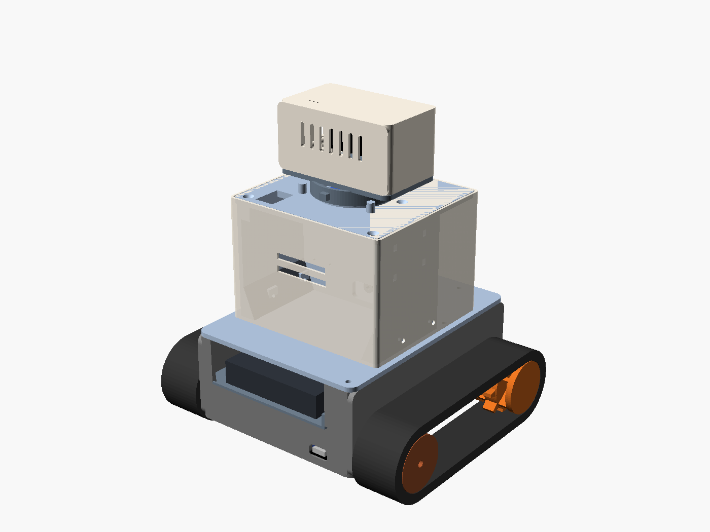
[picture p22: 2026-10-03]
docs/img/cad_assembly.png

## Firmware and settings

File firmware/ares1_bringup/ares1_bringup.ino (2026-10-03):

// ARES-1 硬體上線測試（Arduino-ESP32 核心 3.x）
//
// ⚠ 這支程式「還沒有在實機上編譯測試過」，腳位全部依推估板型，
//    請先對照 ares1_pins.h 的說明確認你的 ESP32-S3-CAM 絲印再上傳。
//
// 電源是學員自備的 PD 行動電源 → CH224K 誘騙 9 V。注意：
//   - CH224K 第一次一定要先單獨量到 9.0 V 再接上車（出廠常是 20 V）。
//   - 9 V 不會隨行動電源電量慢慢掉；電量看行動電源自己的燈。GPIO1 量的是「PD 有沒有成功」。
//   - 行動電源電流太小會自動關機，所以這支程式不用 deep sleep。
//
// Arduino IDE 設定：開發板選 ESP32S3 Dev Module、Flash 16MB、PSRAM 選 OPI PSRAM、
//   USB CDC On Boot = Disabled，接「TTL」那個 USB-C 上傳（OTG 口的腳位拿去接編碼器了）。
//
// 序列埠指令（115200）：
//   w / s / a / d  前進／後退／左轉／右轉（放開不會自己停，按空白鍵停）
//   空白           停車
//   h              頭部 ±45° 掃描一次        c  頭部置中
//   t              喇叭嗶一聲                m  麥克風音量條 3 秒
//   b              讀 9 V 電源               e  編碼器計數與轉速（按一次印 3 秒）
#include <Arduino.h>
#include <ESP_I2S.h>
#include "ares1_pins.h"

// ---------------- 馬達（DRV8870：IN1=PWM、IN2=0 前進；反過來後退；兩腳 0 滑行） ----------------
constexpr uint32_t MOTOR_FREQ = 20000;   // 20 kHz，聽不到嘯叫
constexpr uint8_t  MOTOR_RES  = 10;      // 0–1023
constexpr float    MOTOR_MAX  = 0.66f;   // 6 V 馬達接 9 V：平均 ≈ 6 V。不要拿掉，馬達會過熱
constexpr float    RAMP_PER_S = 4.0f;    // 0→全速 0.25 s，遠低於穩定性分析的 2.4 m/s² 上限
constexpr bool     INVERT_L   = false;   // 裝好後方向相反就改這兩個
constexpr bool     INVERT_R   = true;    // 左右馬達鏡像安裝，右邊預設反轉

float curL = 0, curR = 0, tgtL = 0, tgtR = 0;

void motorWrite(int in1, int in2, float v) {
  v = constrain(v, -1.0f, 1.0f) * MOTOR_MAX;
  uint32_t duty = (uint32_t)(fabsf(v) * ((1 << MOTOR_RES) - 1));
  if (v > 0.01f)       { ledcWrite(in1, duty); ledcWrite(in2, 0); }
  else if (v < -0.01f) { ledcWrite(in1, 0);    ledcWrite(in2, duty); }
  else                 { ledcWrite(in1, 0);    ledcWrite(in2, 0); }
}

void updateMotors(float dt) {
  auto step = [dt](float &cur, float tgt) {
    float d = tgt - cur, m = RAMP_PER_S * dt;
    cur += constrain(d, -m, m);
  };
  step(curL, tgtL);
  step(curR, tgtR);
  motorWrite(PIN_ML_IN1, PIN_ML_IN2, INVERT_L ? -curL : curL);
  motorWrite(PIN_MR_IN1, PIN_MR_IN2, INVERT_R ? -curR : curR);
}

// ---------------- 堵轉保護（20 W 行動電源撐不住兩邊同時堵轉） ----------------
// 指令 > 30% 但編碼器 0.3 s 都沒有脈衝 → 卡住了（或編碼器沒接），兩邊一起斷電。
constexpr bool     STALL_GUARD = true;     // 編碼器還沒接好時先改成 false
constexpr uint32_t STALL_MS    = 300;
constexpr float    STALL_CMD   = 0.30f;

// ---------------- 頭部伺服 SG92R ----------------
constexpr uint32_t SERVO_FREQ = 50;
constexpr uint8_t  SERVO_RES  = 14;          // 20 ms 週期 = 16384 格
constexpr int      SERVO_CENTER_US  = 1500;  // 待校正：頭正對前方時的脈寬
constexpr float    SERVO_US_PER_DEG = 10.5f; // SG9x 約 500–2400 µs 對 180°，待校正

void headYaw(float deg) {
  deg = constrain(deg, (float)-HEAD_YAW_MAX_DEG, (float)HEAD_YAW_MAX_DEG);
  float us = SERVO_CENTER_US + deg * SERVO_US_PER_DEG;   // 正值＝頭往車子左側轉；裝反就改正負號
  ledcWrite(PIN_SERVO, (uint32_t)(us / 20000.0f * ((1 << SERVO_RES) - 1)));
}

// ---------------- 霍爾編碼器（先只數 A 相，方向取自馬達指令） ----------------
volatile uint32_t encL = 0, encR = 0;
void IRAM_ATTR isrEncL() { encL++; }
void IRAM_ATTR isrEncR() { encR++; }

void encoderBegin() {
  pinMode(PIN_ENC_LA, INPUT);            // 編碼器板本身有上拉；3.3 V 供電
  pinMode(PIN_ENC_RA, INPUT);
  attachInterrupt(digitalPinToInterrupt(PIN_ENC_LA), isrEncL, RISING);
  attachInterrupt(digitalPinToInterrupt(PIN_ENC_RA), isrEncR, RISING);
}

// ---------------- 狀態燈（板載 WS2812） ----------------
void statusLed(uint8_t r, uint8_t g, uint8_t b) { rgbLedWrite(PIN_RGB, r, g, b); }

bool stalled(float cur, volatile uint32_t &enc, uint32_t &last, uint32_t &t0, uint32_t now) {
  uint32_t e = enc;
  if (fabsf(cur) < STALL_CMD || e != last) { last = e; t0 = now; return false; }
  return now - t0 > STALL_MS;
}

// ---------------- 9 V 電源 ----------------
float readV9() {
  uint32_t mv = 0;
  for (int i = 0; i < 16; i++) mv += analogReadMilliVolts(PIN_V9);
  return mv / 16.0f / 1000.0f * V9_RATIO;
}
void powerReport(float v) {
  if (v < 3.0f)          Serial.printf("9 V = %.2f V：沒有接行動電源（只有 USB 供電，馬達不會動）\n", v);
  else if (v < V9_STOP)  Serial.printf("9 V = %.2f V：PD 沒成功！換一條 C-to-C 線，或換支援 PD（9V⎓2A）的行動電源\n", v);
  else if (v < V9_WARN)  Serial.printf("9 V = %.2f V：偏低，檢查接線或行動電源快沒電了\n", v);
  else                   Serial.printf("9 V = %.2f V：正常\n", v);
}

// ---------------- 音訊：I2S0 全雙工（麥克風與功放共用 BCLK/WS） ----------------
I2SClass i2s;
constexpr uint32_t SAMPLE_RATE = 16000;
int32_t audioBuf[2 * 256];                   // 立體聲 32-bit 槽位

bool audioBegin() {
  i2s.setPins(PIN_I2S_BCLK, PIN_I2S_WS, PIN_I2S_DOUT, PIN_I2S_DIN);
  return i2s.begin(I2S_MODE_STD, SAMPLE_RATE, I2S_DATA_BIT_WIDTH_32BIT, I2S_SLOT_MODE_STEREO);
}

void beep(int freq, int ms) {
  int left = SAMPLE_RATE * ms / 1000;
  float ph = 0, dph = 2 * PI * freq / SAMPLE_RATE;
  while (left > 0) {
    int k = min(left, 256);
    for (int i = 0; i < k; i++) {
      int32_t s = (int32_t)(sinf(ph) * 0.15f * 2147483647.0f);   // 15% 音量，避免電流尖峰
      audioBuf[2 * i] = s; audioBuf[2 * i + 1] = s;
      ph += dph; if (ph > 2 * PI) ph -= 2 * PI;
    }
    i2s.write((uint8_t *)audioBuf, k * 2 * sizeof(int32_t));
    left -= k;
  }
}

float micLevel() {
  size_t got = i2s.readBytes((char *)audioBuf, sizeof(audioBuf));
  int frames = got / (2 * sizeof(int32_t));
  if (frames == 0) return 0;
  double acc = 0;
  for (int i = 0; i < frames; i++) {
    float s = (audioBuf[2 * i] >> 8) / 8388608.0f;   // INMP441：24-bit 資料在 32-bit 槽位高位，左聲道
    acc += s * s;
  }
  return sqrtf(acc / frames);
}

// ---------------- 主程式 ----------------
void setup() {
  Serial.begin(115200);
  delay(300);
  ledcAttach(PIN_ML_IN1, MOTOR_FREQ, MOTOR_RES);
  ledcAttach(PIN_ML_IN2, MOTOR_FREQ, MOTOR_RES);
  ledcAttach(PIN_MR_IN1, MOTOR_FREQ, MOTOR_RES);
  ledcAttach(PIN_MR_IN2, MOTOR_FREQ, MOTOR_RES);
  updateMotors(0);
  ledcAttach(PIN_SERVO, SERVO_FREQ, SERVO_RES);
  headYaw(0);
  analogReadResolution(12);
  encoderBegin();
  statusLed(0, 8, 0);
  bool ok = audioBegin();
  Serial.printf("\nARES-1 上線測試  I2S=%s\n", ok ? "OK" : "失敗（檢查腳位）");
  powerReport(readV9());
  Serial.println("w/s/a/d 移動、空白停、h 掃頭、c 置中、t 嗶聲、m 麥克風、b 9 V 電源、e 編碼器");
  if (ok) beep(1200, 120);
}

void loop() {
  static uint32_t last = millis(), lastBat = 0;
  static uint32_t encLastL = 0, encLastR = 0, stallT0L = 0, stallT0R = 0;
  uint32_t now = millis();
  float dt = (now - last) / 1000.0f;
  last = now;

  if (Serial.available()) {
    char c = Serial.read();
    const float V = 0.6f;
    switch (c) {
      case 'w': tgtL = V;  tgtR = V;  break;
      case 's': tgtL = -V; tgtR = -V; break;
      case 'a': tgtL = -V; tgtR = V;  break;
      case 'd': tgtL = V;  tgtR = -V; break;
      case ' ': tgtL = 0;  tgtR = 0;  break;
      case 'c': headYaw(0); break;
      case 'h':
        for (int d = 0; d <= HEAD_YAW_MAX_DEG; d += 3) { headYaw(d); delay(20); }
        for (int d = HEAD_YAW_MAX_DEG; d >= -HEAD_YAW_MAX_DEG; d -= 3) { headYaw(d); delay(20); }
        for (int d = -HEAD_YAW_MAX_DEG; d <= 0; d += 3) { headYaw(d); delay(20); }
        break;
      case 't': beep(880, 200); beep(1320, 200); break;
      case 'm':
        for (uint32_t t0 = millis(); millis() - t0 < 3000;) {
          int bars = constrain((int)(micLevel() * 400), 0, 40);
          Serial.printf("\r麥克風 |%-40.*s|", bars, "########################################");
        }
        Serial.println();
        break;
      case 'b': powerReport(readV9()); break;
      case 'e':
        for (int i = 0; i < 6; i++) {
          uint32_t l0 = encL, r0 = encR;
          delay(500);
          Serial.printf("編碼器 左 %lu（%+.0f 脈衝/s）  右 %lu（%+.0f 脈衝/s）\n",
                        (unsigned long)encL, (encL - l0) * 2.0f * (curL >= 0 ? 1 : -1),
                        (unsigned long)encR, (encR - r0) * 2.0f * (curR >= 0 ? 1 : -1));
        }
        break;
    }
  }

  if (now - lastBat > 1000) {
    lastBat = now;
    float v = readV9();
    if (v < V9_STOP && v > 3.0f) {             // > 3 V：只接 USB 時不誤判
      tgtL = tgtR = 0;
      statusLed(16, 0, 0);
      powerReport(v);
    } else if (v < V9_WARN && v > 3.0f) {
      statusLed(12, 6, 0);
      powerReport(v);
    }
  }
  if (STALL_GUARD && (stalled(curL, encL, encLastL, stallT0L, now) | stalled(curR, encR, encLastR, stallT0R, now))) {
    tgtL = tgtR = curL = curR = 0;
    statusLed(16, 0, 8);
    Serial.println("堵轉保護：編碼器 0.3 s 沒有脈衝，已斷電（卡住了？編碼器沒接就把 STALL_GUARD 改 false）");
  }
  updateMotors(dt);
  delay(5);
}

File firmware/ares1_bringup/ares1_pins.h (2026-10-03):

// ARES-1 腳位定義 — GOOUUU ESP32-S3-CAM（ESP32-S3-N16R8）
//
// 已依商品圖排針絲印核對（左排：3V3 EN 4 5 6 7 15 16 17 18 8 3 46 9 10 11 12 13 14 5V；
// 右排：TX0 RX0 1 2 42 41 40 39 38 37 36 35 0 45 48 47 21 20 19 GND）。
//
// 不能用的腳：
//   - GPIO4–13、15–18：相機（與 ESP32-S3-EYE 相同對應；CameraWebServer 範例選 CAMERA_MODEL_ESP32S3_EYE）
//   - GPIO35/36/37：排針上有拉出來，但 N16R8 的 Octal PSRAM 在用，接了會當機
//   - GPIO43/44：TX0/RX0 接 CH340（TTL 口），用來燒錄與看序列埠
//   - GPIO0（BOOT）、GPIO45（Flash 電壓）：strapping，不接
// 燒錄請用「TTL」那個 USB-C。OTG 口的 GPIO19/20 已拿去接編碼器。
#pragma once

// 電源：PD 行動電源 → CH224K 誘騙 9 V → 開關 → 9V_SW（馬達）＋ Mini560 5 V（其他全部）
// 9 V 監測：9V_SW —100k— GPIO1 —33k— GND（9 V → 2.23 V；PD 沒成功只有 5 V → 1.24 V）
constexpr int PIN_V9      = 1;     // ADC1_CH0（ADC2 在 Wi-Fi 開啟時不能用）
constexpr float V9_RATIO  = (100.0f + 33.0f) / 33.0f;

// DRV8870 雙路模組（放底盤右側：端子朝車身中央、VM 在後端；VO 不接、可變電阻轉到最小）
//   OUT1/2 → 右馬達（車頭）  OUT3/4 → 左馬達（車尾）
constexpr int PIN_MR_IN1 = 47;     // 模組 IN1
constexpr int PIN_MR_IN2 = 38;     // 模組 IN2
constexpr int PIN_ML_IN1 = 14;     // 模組 IN3
constexpr int PIN_ML_IN2 = 21;     // 模組 IN4

// 霍爾編碼器（VCC 一定要 3.3 V：由 AMS1117-3.3 供電，不用驅動板 VO；每條訊號串 1 kΩ）
constexpr int PIN_ENC_LA = 19;     // 左馬達 A 相（OTG 口 D−）
constexpr int PIN_ENC_RA = 20;     // 右馬達 A 相（OTG 口 D+）
constexpr int PIN_ENC_LB = 3;      // 左馬達 B 相（選配；strapping 腳但預設 eFuse 下不影響開機）
constexpr int PIN_ENC_RB = 46;     // 右馬達 B 相（選配；⚠ 燒錄時必須為低電位，燒不進去就拔 J2）
constexpr bool USE_ENC_B = false;  // 先只用 A 相，方向取自馬達指令

// SG92R 頭部 Yaw（ESP32 直接輸出 50 Hz，不需要 LU9685 或伺服驅動板）
constexpr int PIN_SERVO  = 2;

// I2S0 全雙工：麥克風與功放共用 BCLK / WS
constexpr int PIN_I2S_BCLK = 39;   // INMP441 SCK ＋ MAX98357A BCLK
constexpr int PIN_I2S_WS   = 40;   // INMP441 WS  ＋ MAX98357A LRC
constexpr int PIN_I2S_DOUT = 41;   // → MAX98357A DIN
constexpr int PIN_I2S_DIN  = 42;   // ← INMP441 SD（L/R 接 GND＝左聲道）

// 板載 WS2812 RGB（狀態燈）
constexpr int PIN_RGB = 48;

// 機構與安全參數（與 web/index.html、cad/ares1_params.scad 相同）
constexpr int   HEAD_YAW_MAX_DEG = 45;     // 軟體限位；機械限位 ±55°
constexpr float ACCEL_LIMIT      = 2.4f;   // m/s²，穩定性計算建議值
constexpr float V9_WARN          = 8.3f;   // 9 V 掉太多：行動電源快沒電、線太細或接觸不良
constexpr float V9_STOP          = 7.0f;   // 停車：PD 沒成功（只有 5 V）或電壓崩了（DRV8870 在 6.5 V 以下欠壓）
constexpr float MOTOR_V_RATED    = 6.0f;   // JGA25-370 6 V 版，9 V 供電時 PWM 上限 = 6 / 9 ≈ 0.66

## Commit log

2026-09-27 Add ARES-1 upright tracked rover design: 3D web model, CAD, docs
    Main version B (diagonal motors, upright body, yaw-only head):
    - web/index.html: interactive Three.js engineering page with views,
    explode, x-ray/internal/section, wiring overlay, part inspector,
    parameter editing, interference and stability checks, camera FOV,
    head sweep and a 14-step assembly walkthrough (Traditional Chinese)
    - cad/: parametric OpenSCAD part library sharing the web parameters,
    build script and 16 STLs for the default configuration
    - docs/DESIGN.md: layout comparison (A/B/C), rotation mechanism, neck
    harness routing, stability math, power tree, GPIO allocation, wiring
    table, dimension status, risks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
    [ares1.scad, ares1_params.scad, battery_sled.stl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]
2026-09-28 Update design from part photos; add encoders and battery-swap demo
    Photos confirmed the GOOUUU ESP32-S3-CAM pinout, DRV8870 module
    layout, JGA25-370 drawing, MAX98357A/INMP441 pinouts and SG92R size.
    - Head: the OV2640 sits on its FPC about 20 mm toward the antenna end,
    so the real lens now forms the right eye (left eye is decorative)
    - Wiring: Hall encoder A phases on GPIO19/20 (flash via TTL port),
    optional B on GPIO3/46, encoder VCC from the driver's LM317M set to
    3.3 V with 1 kOhm series resistors; J2 becomes 8-pin, neck harness
    15-core; GPIO table rechecked against the board silkscreen
    - Chassis: motor M3 holes vertical so the encoder connector faces up,
    cradle moved to the m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
    [ares1.scad, ares1_params.scad, battery_sled.stl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]
2026-10-03 Switch power to student PD power banks with a rear-opening battery bay
    The chassis becomes two-level: motors, driver and a new power zone stay on
    the lower level, and the whole upper level is a bay for a student-supplied
    power bank (85 x 27.5 usable, open at the rear so long banks can stick out).
    The body shrinks from 96 to 78 mm so overall height is unchanged.
    Power path: PD power bank -> CH224K (9 V) -> switch -> DRV8870 + Mini560
    5 V; encoders get 3.3 V from an AMS1117 instead of the driver's VO, which
    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
    [ares1.scad, ares1_params.scad, bank_spacer.stl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]
2026-10-06 Add fit-test kit, make tol work, and fix parts that needed supports
    The tol clearance in ares1_params.scad was never used, so a print that
    came out tight had nothing to adjust. Sliding and press fits now derive
    from tol (default 0.3 keeps the previous sizes) and the heat-insert
    holes from a new insertD.
    New cad/stl/fit/ kit (about an hour of printing) checks the real parts
    before the big prints: clearance comb, heat-insert sizes, motor mount,
    D-shaft hub, three track links, servo neck and head skirt, ESP32 frame,
    DRV8870 hole template.
    An overhang scan of every STL found parts that would not print cleanly:
    - sprocket/idler floated 1 mm above the bed apart from the hub; now
    printed outer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
    [ares1.scad, ares1_params.scad, body_shell.stl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]
2026-10-06 Print guide: use the vendor track kit instead of printed tracks
    The camp bought modular tracks and wheels, so sprocket, idler, track
    links and their fit tests drop off the print list. The tub now waits for
    the kit's wheel and track dimensions, since wheel size sets the axle
    height, motor holes, idler slot and tray height.
    Claude-Session: https://claude.ai/code/session_015NxpwvZRLexra2GcgGNciH
2026-10-07 Switch ARES-1 to laser-cut 3 mm plywood
    The whole structure is now 46 panels of 3 mm basswood plywood joined
    with tabs and white glue; no 3D-printed parts remain. Track and wheels
    come from the vendor kit.
    - Web model: panel generator with auto-cut mortises, T-slot nut joints,
    per-panel mass, and engraved part codes on hidden faces
    - New laser tab: kerf compensation, multi-strategy nesting, SVG/DXF
    export, kerf/thickness test coupon, sheet presets and name tag
    - Checks: every tab has a slot, holes keep 0.8 mm web, nesting fits
    the sheet; departure angle and body layout fixed for plywood
    - laser/: default SVG/DXF sets for 400x300, 600x400, 300x200 plus a
    test coupon, parts.csv and a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
    [ARES1_300x200_sheet1of5.dxf, ARES1_300x200_sheet2of5.dxf, ARES1_300x200_sheet3of5.dxf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]
2026-10-07 Laser tab: one-click zip of all SVG/DXF, downloads that work in the viewer
    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
2026-10-08 Laser: true-shape nesting for 30x45 sheets, fix head skirt clash
    - Nest real part shapes on a 0.5 mm raster so small parts drop into
    big holes and notches; nested parts are cut first
    - Batch several robots on one layout: 3 robots fit on 5 sheets of
    30x45 cm instead of 6; optional smaller last sheet (e.g. 38x27)
    - Default sheet is now 450x300 with 3 mm margin and 1.5 mm spacing
    - New check scans every plywood panel in 3D for overlaps; it caught
    the top head skirt ring hitting the front/back head walls, fixed by
    notching the wall bottoms and moving the floor tabs
    - Score marks are clipped to the part they belong to
    - laser/ now ships 30x45 sets for one robot (2 sheets) and three
    robo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
    [ARES1_300x200_sheet1of5.dxf, ARES1_300x200_sheet2of5.dxf, ARES1_300x200_sheet3of5.dxf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]
2026-10-21 Second version: scale up chassis 1.5x, body 1.4x, head 1.2x; 2.7 mm ply
    - New "overall size" sliders scale chassis, body and head relative to
    the first build; wheelbase snaps to a whole number of track links
    - Defaults: 233 x 216 x 254 mm, 2.7 mm measured plywood, 0.1 mm slot
    clearance per side; one robot nests on three 30 x 45 cm sheets
    - Wire channel widens when the body is narrower than the chassis;
    T-slots and strap slots scale with chassis length; layout A no
    longer forces a narrower chassis
    - Export cleanup for laser software: engraved text thickened 0.1 mm,
    slivers under 0.5 mm dropped, duplicate vertices removed, explicit
    vertex flags in DXF
    - laser/ regenerated for the s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
2026-10-21 Body: full 5x7 cm perfboard on standoffs instead of the cut-down board
    - Uncut 70 x 50 FR-4 perfboard mounted on the right wing with four M2
    nylon standoffs (8 mm), component side facing the middle; lies
    long-side front-to-back when the body is deep enough, upright
    otherwise, and the check reports when it cannot fit (body < 1.15x)
    - Right wing gets the four M2 holes instead of zip-tie slots
    - Model, part info, assembly step, BOM and design doc updated;
    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
